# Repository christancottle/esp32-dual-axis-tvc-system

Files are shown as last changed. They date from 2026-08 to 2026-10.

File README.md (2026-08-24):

# ESP32 Dual-Axis Thrust Vector Control (TVC) Flight Computer

An embedded 6-DOF flight computer designed for active thrust vector control, real-time wireless ground station telemetry, and high-rate flash logging. Built around the **ESP32**, **MPU-6050** IMU, and **BMP280** barometric sensor.

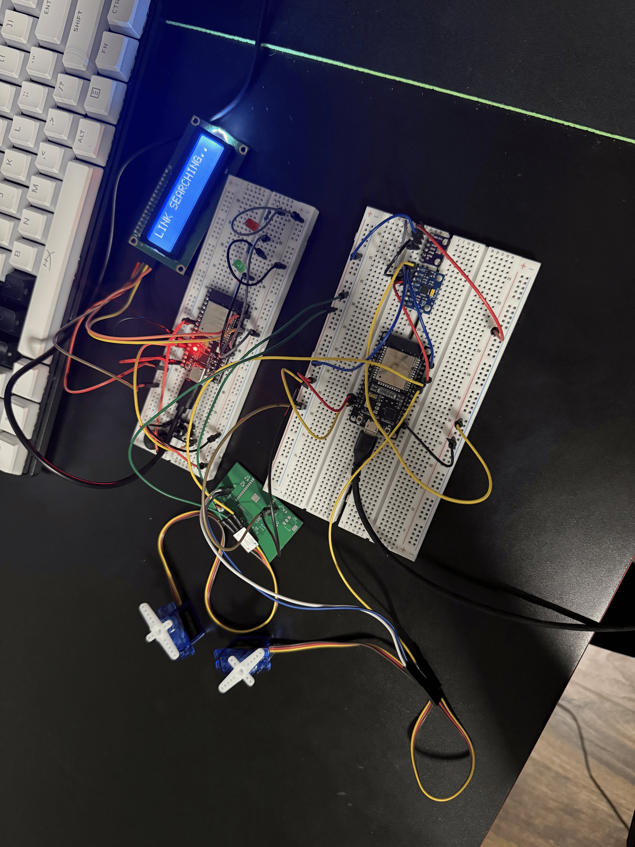
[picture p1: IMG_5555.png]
Flight Telemetry Plot


---

## Key Features

* **Dual-Axis Active Stabilization:** Controls Pitch and Yaw servos using sensor fusion logic bounded within $\pm 30^\circ$ deflection limits.
* **Low-Noise Filter Pipeline:** Employs an Exponential Moving Average (EMA) low-pass filter on orientation angles to eliminate motor servo jitter caused by high-G accelerometer noise.
* **High-Rate Flash Logging:** Writes telemetry data at ~30 Hz directly to onboard **LittleFS** physical flash memory with immediate buffer flushing (`logFile.flush()`) to prevent data loss during power brownouts.
* **5 Hz Wireless Telemetry:** Broadcasts telemetry packets over **ESP-NOW** to a ground telemetry station.
* **Deterministic State Machine:** Robust state engine (`ARMED` $\rightarrow$ `FLIGHT` $\rightarrow$ `DESCENT` $\rightarrow$ `LANDED`) with manual serial debug overrides (`reset` & `dump`).

---

## Hardware Specifications & Pinout

| Component | Interface / Pin | Description |
| :--- | :--- | :--- |
| **Microcontroller** | ESP32-WROOM-32 | Dual-core @ 240 MHz, LittleFS, ESP-NOW Wireless |
| **Pitch Servo** | GPIO 18 (PWM) | Dedicated PWM Timer 0 allocation (50 Hz) |
| **Yaw Servo** | GPIO 19 (PWM) | Dedicated PWM Timer 0 allocation (50 Hz) |
| **IMU (MPU-6050)** | I2C (SDA: 21, SCL: 22) | 6-DOF Accelerometer & Gyroscope ($\pm 8g$ range) |
| **Barometer (BMP280)**| I2C (Address 0x76/0x77) | High-precision altitude tracking with I2C recovery |

---

## Telemetry Log & Flight Performance

Flight performance data captured during test logging (stored in [`telemetry/espnowfile.csv`](espnowfile.csv)):

* **Peak Altitude:** `0.61 m` (Barometric filtered)
* **Peak Acceleration:** `1.40 g`
* **Log Sample Rate:** ~30 Hz (~33ms log interval)
* **Attitude Limits:** Pitch range $[-5.4^\circ, +35.7^\circ]$, Yaw range $[-0.8^\circ, +15.9^\circ]$

---

## Testing & Debugging Strategy

Building a custom avionics stack requires isolated validation of hardware, firmware, and wireless protocols before integration. The system was engineered and verified using a modular, step-by-step testing process:

### 1. Wireless Telemetry & Ground Station Validation
* **Mock Data Injection:** Before binding the actual ESP32 flight computer over ESP-NOW, the ground station display and receiving logic were validated by broadcasting simulated sine waves and randomized telemetry packets from a secondary microelectronics test rig.
* **Link Quality & Range Testing:** Verified packet delivery rates and RSSI stability to ensure zero-loss packet parsing prior to mounting hardware.

### 2. Sensor Calibration & Noise Filtering
* **Static Baseline Bench Calibration:** The BMP280 barometric pressure sensor was calibrated against local ambient pressure across multiple 10-sample rolling averages to establish an accurate zero-altitude reference.
* **Jitter Mitigation (EMA Filtering):** Raw MPU-6050 accelerometer readings exhibited high-frequency noise that translated into servo chatter. An Exponential Moving Average (EMA) low-pass filter ($\alpha = 0.15$) was implemented on the Yaw axis, successfully smoothing actuation without introducing control lag.

### 3. Flash Storage & Crash Resilience
* **LittleFS File Integrity Tests:** Initial testing revealed buffered writes were lost when power dropped during reset. The flight loop was updated to enforce immediate physical commits (`logFile.flush()`) right after writing telemetry rows.
* **Serial Log Dumping:** Integrated non-blocking serial commands (`dump` and `reset`) to easily extract flash logs to `.csv` format and re-zero altitude baselines between bench tests.

### 4. Hardware Safety & Servo Management
* **Shared PWM Timer Allocation:** Consolidated both servo channels onto ESP32 PWM Timer 0 to resolve hardware timer allocation conflicts and prevent signal dropping.
* **State Machine Latches:** Added persistent lock states in `LANDED` mode to keep servos centered and prevent unintentional actuation after flight completion.

---

## Repository Structure

```text
├── firmware/
│   └── TVC_Flight_Computer.ino     # Main ESP32 flight software
├── telemetry/
│   ├── espnowfile.csv              # Raw logged telemetry CSV dataset
│   └── plot_telemetry.py           # Python data analysis & plotting script
├── assets/
│   └── flight_telemetry_clean.png  # Generated telemetry visualization
└── README.md

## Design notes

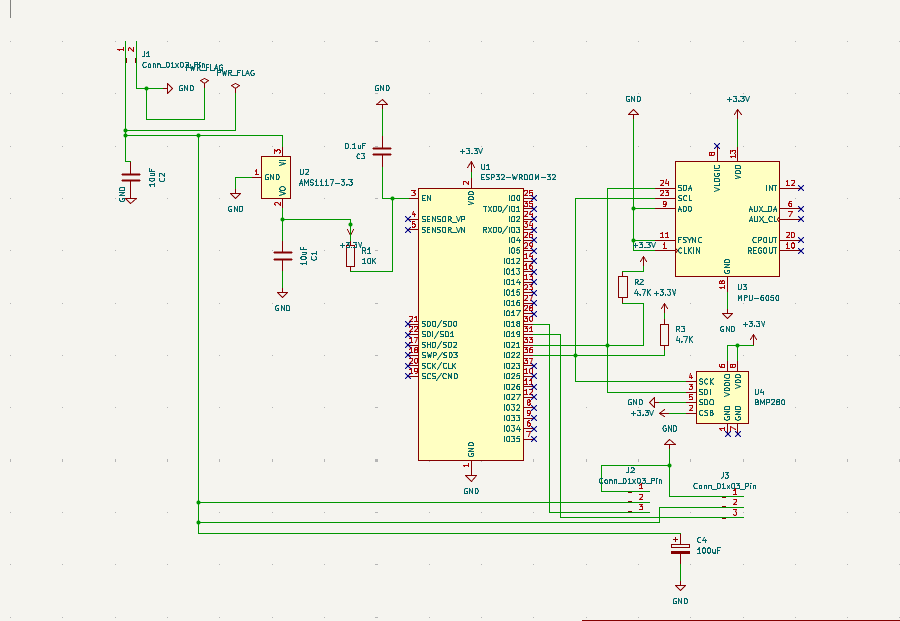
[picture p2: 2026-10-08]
Custom PCB Schematic.png

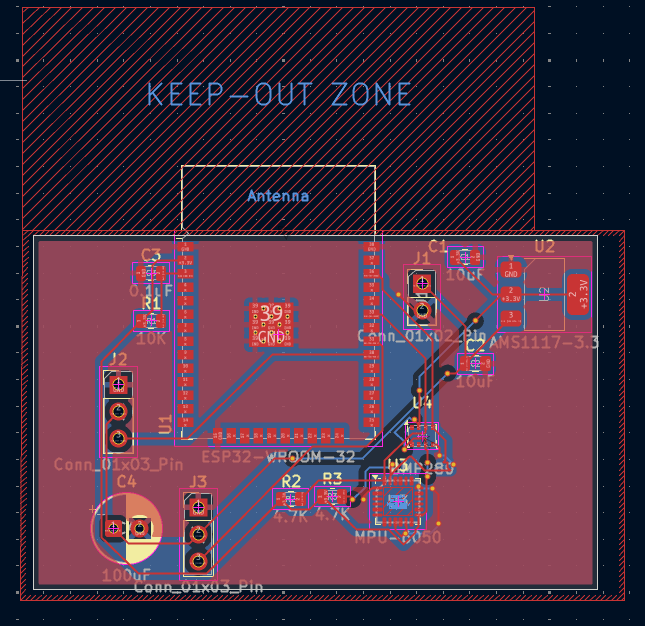
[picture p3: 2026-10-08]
Custom PCB editor.png

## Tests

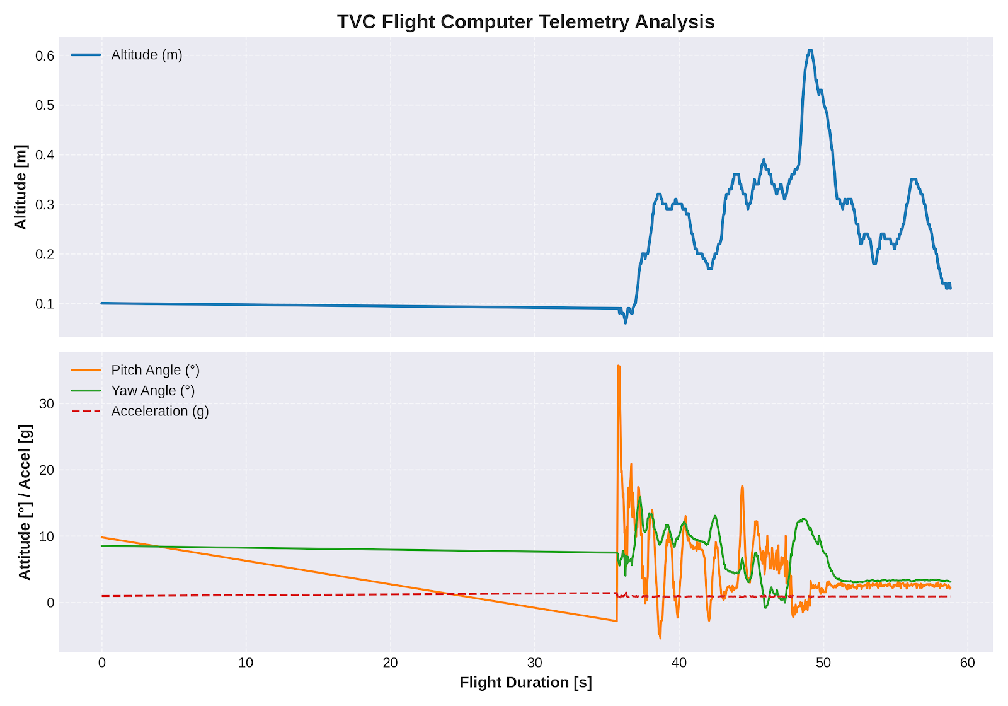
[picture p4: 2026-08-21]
Test_Run_Plots.png

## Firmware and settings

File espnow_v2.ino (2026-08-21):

#include <WiFi.h>
#include <esp_now.h>
#include <Wire.h>
#include <Adafruit_MPU6050.h>
#include <Adafruit_BMP280.h>
#include <Adafruit_Sensor.h>
#include <ESP32Servo.h>
#include <LittleFS.h>

// --- HARDWARE PIN DEFINITIONS ---
#define SERVO_PITCH_PIN 18 // Header J2
#define SERVO_YAW_PIN   19 // Header J3
#define SERVO_CENTER    90
#define SERVO_MAX_DEF   30

// --- GROUND STATION MAC ADDRESS ---
uint8_t broadcastAddress[] = {0xD4, 0xE9, 0xF4, 0xE1, 0xEC, 0xC0};

typedef struct TelemetryPacket {
    float pitch;
    float yaw;
    float altitude;
    uint8_t flightState; // 0=IDLE, 1=ARMED, 2=FLIGHT, 3=DESCENT, 4=LANDED
} TelemetryPacket;

TelemetryPacket txData;
esp_now_peer_info_t peerInfo;

Adafruit_MPU6050 mpu;
Adafruit_BMP280 bmp;
File logFile;

Servo pitchServo;
Servo yawServo;

unsigned long lastTxTime = 0;
unsigned long stateTimer = 0; 
float basePressure = 1013.25;
float maxAltitude = 0.0f;
float currentAltitude = 0.0f;
float filteredYaw = 0.0f; // EMA Filter memory for Yaw axis
bool bmpAvailable = false;

// Updated callback signature for ESP32 Core 3.3.8 / 3.x
void OnDataSent(const wifi_tx_info_t *tx_info, esp_now_send_status_t status) {
  // ESP-NOW Send Callback
}

// Full System & Altitude Baseline Reset
void resetSystem() {
  if (bmpAvailable) {
    float totalPressure = 0;
    for (int i = 0; i < 10; i++) {
      totalPressure += bmp.readPressure() / 100.0F;
      delay(10);
    }
    basePressure = totalPressure / 10.0F;
  }
  
  maxAltitude = 0.0f;
  currentAltitude = 0.0f;
  filteredYaw = 0.0f;
  txData.altitude = 0.0f;
  txData.flightState = 1; // ARMED mode
  stateTimer = millis();

  // Attach and center BOTH servos on reset
  pitchServo.write(SERVO_CENTER);
  yawServo.write(SERVO_CENTER);

  // LittleFS Log Initialization
  logFile = LittleFS.open("/flight_log.csv", FILE_WRITE);
  if (logFile) {
    logFile.println("Time_ms,State,Pitch_deg,Yaw_deg,Alt_m,AccMag");
    logFile.flush(); // Ensure header is written immediately
  }

  Serial.println("\n*** BENCH RESET COMPLETE: SERVOS CENTERED & ALTITUDE ZEROED ***\n");
}

void dumpFlashData() {
  Serial.println("\n--- DUMPING TELEMETRY LOG FROM LITTLEFS FLASH ---");
  
  // Close write buffer before reading to prevent file locks
  if (logFile) {
    logFile.flush();
    logFile.close();
  }

  File file = LittleFS.open("/flight_log.csv", FILE_READ);
  if (!file) {
    Serial.println("❌ Failed to open /flight_log.csv");
    return;
  }
  while (file.available()) {
    Serial.write(file.read());
  }
  file.close();
  Serial.println("--- END OF FLIGHT LOG DUMP ---\n");

  // Re-open in append mode for future operations
  logFile = LittleFS.open("/flight_log.csv", FILE_APPEND);
}

void setup() {
  Serial.begin(115200);

  // 1. Initialize LittleFS Flash Storage
  if (!LittleFS.begin(true)) {
    Serial.println("❌ LittleFS Storage Mount Failed!");
  } else {
    Serial.println("✅ LittleFS Storage Online.");
  }

  // 2. Optimized Servo Timer Allocation (Shared Timer 0 to eliminate jitter)
  ESP32PWM::allocateTimer(0);
  pitchServo.setPeriodHertz(50);
  yawServo.setPeriodHertz(50);
  
  pitchServo.attach(SERVO_PITCH_PIN, 500, 2400);
  yawServo.attach(SERVO_YAW_PIN, 500, 2400);

  pitchServo.write(SERVO_CENTER);
  yawServo.write(SERVO_CENTER);

  // 3. Initialize I2C Peripherals
  Wire.begin(21, 22);

  if (!mpu.begin()) {
    Serial.println("Warning: MPU6050 not detected!");
  } else {
    mpu.setAccelerometerRange(MPU6050_RANGE_8_G);
    Serial.println("✅ MPU6050 Online!");
  }

  if (bmp.begin(0x76) || bmp.begin(0x77)) {
    bmpAvailable = true;
    bmp.setSampling(Adafruit_BMP280::MODE_NORMAL,     
                    Adafruit_BMP280::SAMPLING_X2,     
                    Adafruit_BMP280::SAMPLING_X16,    
                    Adafruit_BMP280::FILTER_X16,      
                    Adafruit_BMP280::STANDBY_MS_1);   
    Serial.println("✅ BMP280 Online!");
  } else {
    Serial.println("Warning: BMP280 not detected!");
  }

  // 4. Initialize ESP-NOW
  WiFi.mode(WIFI_STA);

  if (esp_now_init() != ESP_OK) {
    Serial.println("Error initializing ESP-NOW");
    return;
  }

  esp_now_register_send_cb(OnDataSent);

  memcpy(peerInfo.peer_addr, broadcastAddress, 6);
  peerInfo.channel = 0;  
  peerInfo.encrypt = false;
  
  if (esp_now_add_peer(&peerInfo) != ESP_OK) {
    Serial.println("Failed to add peer");
    return;
  }

  resetSystem();
}

void loop() {
  // Serial command parser
  if (Serial.available() > 0) {
    String input = Serial.readStringUntil('\n');
    input.trim();
    if (input.equalsIgnoreCase("reset")) {
      resetSystem();
    } else if (input.equalsIgnoreCase("dump")) {
      dumpFlashData();
    }
  }

  // Read MPU-6050
  sensors_event_t a, g, temp;
  mpu.getEvent(&a, &g, &temp);

  // Pitch calculation
  txData.pitch = atan2(a.acceleration.y, a.acceleration.z) * 180.0 / M_PI;

  // Yaw calculation with EMA Low-Pass Filter (0.15 alpha) to eliminate motor jitter
  float rawYaw = atan2(-a.acceleration.x, sqrt(a.acceleration.y * a.acceleration.y + a.acceleration.z * a.acceleration.z)) * 180.0 / M_PI;
  filteredYaw = (0.15f * rawYaw) + (0.85f * filteredYaw);
  txData.yaw = filteredYaw;

  // Read BMP280
  if (bmpAvailable) {
    float rawAltitude = bmp.readAltitude(basePressure);

    if (rawAltitude > 2000.0 || isnan(rawAltitude) || rawAltitude < -50.0f) {
      Wire.begin(21, 22);
      bmp.begin(0x76);
      delay(5);
      rawAltitude = bmp.readAltitude(basePressure);
    }

    currentAltitude = (0.80f * currentAltitude) + (0.20f * rawAltitude);
    if (currentAltitude < 0.0f) currentAltitude = 0.0f;
    txData.altitude = currentAltitude;
  }

  // Calculate Total Acceleration Vector Magnitude
  float accelMag = sqrt(a.acceleration.x * a.acceleration.x + 
                        a.acceleration.y * a.acceleration.y + 
                        a.acceleration.z * a.acceleration.z);

  // --- DUAL-AXIS ACTIVE TVC SERVO CONTROL ---
  if (txData.flightState == 1 || txData.flightState == 2) { 
    // Active Stabilization during ARMED & FLIGHT
    int pCmd = constrain(SERVO_CENTER - (int)txData.pitch, SERVO_CENTER - SERVO_MAX_DEF, SERVO_CENTER + SERVO_MAX_DEF);
    int yCmd = constrain(SERVO_CENTER + (int)txData.yaw,   SERVO_CENTER - SERVO_MAX_DEF, SERVO_CENTER + SERVO_MAX_DEF);

    pitchServo.write(pCmd);
    yawServo.write(yCmd);
  } else {
    // Lock Servos Neutral in IDLE, DESCENT, or LANDED
    pitchServo.write(SERVO_CENTER);
    yawServo.write(SERVO_CENTER);
  }

  // --- REVISED FLIGHT STATE MACHINE ---
  switch (txData.flightState) {
    case 0: // IDLE
      break;

    case 1: // ARMED
      if (accelMag > 13.0 || txData.altitude > 0.30f) { 
        txData.flightState = 2; // FLIGHT
        maxAltitude = txData.altitude;
        stateTimer = millis();
        Serial.println(">>> LAUNCH DETECTED! SWITCHING TO FLIGHT MODE <<<");
      }
      break;

    case 2: // FLIGHT / ASCENT
      if (txData.altitude > maxAltitude) {
        maxAltitude = txData.altitude;
        stateTimer = millis(); // Reset timer while ascending
      }

      // Robust bench test apogee criteria: >1.8s peak dwell time AND >0.5m altitude reached
      if (millis() - stateTimer > 1800 && txData.altitude > 0.30f) {
        txData.flightState = 3; // DESCENT
        stateTimer = millis();
        Serial.println(">>> APOGEE DETECTED! ENTERING DESCENT MODE <<<");
      }
      break;

    case 3: // DESCENT
      if (txData.altitude < 0.20f) {
        if (millis() - stateTimer > 1000) {
          txData.flightState = 4; // LANDED
          stateTimer = millis();
          Serial.println(">>> TOUCHDOWN DETECTED! VEHICLE LANDED SAFELY. DATA READY FOR 'dump' <<<");
        }
      } else {
        stateTimer = millis();
      }
      break;

    case 4: // LANDED
      // Hold state safely without auto-resetting
      break;
  }

  // Telemetry Logging with Immediate Flash Flushing
  if (logFile && (txData.flightState == 2 || txData.flightState == 3)) {
    logFile.printf("%lu,%d,%.2f,%.2f,%.2f,%.2f\n", 
                    millis(), txData.flightState, txData.pitch, txData.yaw, txData.altitude, accelMag);
    logFile.flush(); // Critical: Commit buffer directly to physical flash
  }

  // Wireless ESP-NOW Telemetry Transmission (5 Hz)
  if (millis() - lastTxTime >= 200) {
    lastTxTime = millis();
    esp_now_send(broadcastAddress, (uint8_t *) &txData, sizeof(txData));
  }
}

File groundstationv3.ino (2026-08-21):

#include <WiFi.h>
#include <esp_now.h>
#include <Wire.h>
#include <LiquidCrystal_I2C.h>

// --- HARDWARE PIN DEFINITIONS ---
#define GREEN_LED_PIN 16
#define RED_LED_PIN   17
#define BUZZER_PIN    25
#define BUTTON_PIN    13

// LCD Initialization (Default Address: 0x27)
LiquidCrystal_I2C lcd(0x27, 16, 2);

// Telemetry Data Structure - MUST MATCH FLIGHT COMPUTER
typedef struct TelemetryPacket {
    float pitch;
    float yaw;
    float altitude;
    uint8_t flightState; // 0=IDLE, 1=ARMED, 2=FLIGHT, 3=DESCENT
} TelemetryPacket;

TelemetryPacket rxData;
const char* stateNames[] = {"IDLE", "ARM ", "FLY ", "DESC"};

unsigned long lastPacketTime = 0;
uint8_t lastState = 255;
bool greenLedState = false;
bool newPacketReceived = false;

// Audio alert helper function
void beep(int frequency, int durationMs) {
    tone(BUZZER_PIN, frequency, durationMs);
    delay(durationMs);
    noTone(BUZZER_PIN);
}

// ESP-NOW Receive Callback
void OnDataRecv(const esp_now_recv_info *info, const uint8_t *incomingData, int len) {
    memcpy(&rxData, incomingData, sizeof(rxData));
    lastPacketTime = millis();
    newPacketReceived = true;
}

void setup() {
    Serial.begin(115200);

    // Initialize Pins
    pinMode(GREEN_LED_PIN, OUTPUT);
    pinMode(RED_LED_PIN, OUTPUT);
    pinMode(BUZZER_PIN, OUTPUT);
    pinMode(BUTTON_PIN, INPUT_PULLUP);

    // Startup Tones
    beep(1000, 100);
    delay(100);
    beep(1500, 150);

    // Initialize LCD
    Wire.begin(21, 22);
    lcd.init();
    lcd.backlight();
    
    lcd.setCursor(0, 0);
    lcd.print("GND STATION v3.0");
    lcd.setCursor(0, 1);
    lcd.print("AWAITING ESP-NOW");

    // Initialize ESP-NOW
    WiFi.mode(WIFI_STA);

    if (esp_now_init() != ESP_OK) {
        Serial.println("Error initializing ESP-NOW");
        lcd.setCursor(0, 1);
        lcd.print("ESP-NOW ERROR   ");
        return;
    }

    esp_now_register_recv_cb(OnDataRecv);

    delay(1500);
    lcd.clear();
    lcd.setCursor(0, 0);
    lcd.print("LINK SEARCHING..");
}

void loop() {
    // Process Incoming Telemetry
    if (newPacketReceived) {
        newPacketReceived = false;

        // Heartbeat LED
        greenLedState = !greenLedState;
        digitalWrite(GREEN_LED_PIN, greenLedState ? HIGH : LOW);

        // CSV Serial Logging
        Serial.printf("TELEM,%.2f,%.2f,%.2f,%d\n", rxData.pitch, rxData.yaw, rxData.altitude, rxData.flightState);

        // Status LED
        digitalWrite(RED_LED_PIN, (rxData.flightState == 1 || rxData.flightState == 2) ? HIGH : LOW);

        // State Transition Audio Alerts
        if (rxData.flightState != lastState) {
            lastState = rxData.flightState;
            
            if (rxData.flightState == 1) { 
                beep(1200, 100); delay(50); beep(1200, 100); // Double Beep (ARMED)
            } 
            else if (rxData.flightState == 2) { 
                beep(1800, 300); // High Launch Tone (FLIGHT)
            } 
            else if (rxData.flightState == 0) { 
                beep(400, 200);  // Low Return Tone (IDLE)
            }
        }

        // Update LCD Display with Sub-Meter Decimal Precision
        lcd.setCursor(0, 0);
        lcd.printf("P:%5.1f Y:%5.1f", rxData.pitch, rxData.yaw);

        lcd.setCursor(0, 1);
        lcd.printf("A:%4.1fm [%s]", rxData.altitude, stateNames[rxData.flightState]);
    }

    // Link Timeout Detector (3 seconds)
    if (millis() - lastPacketTime > 3000 && lastPacketTime != 0) {
        lcd.setCursor(0, 0);
        lcd.print("  SIGNAL LOST!  ");
        lcd.setCursor(0, 1);
        lcd.print(" CHECK TRANSMIT ");
        digitalWrite(RED_LED_PIN, LOW);
        digitalWrite(GREEN_LED_PIN, LOW);
    }

    // Ground Station Button Trigger
    if (digitalRead(BUTTON_PIN) == LOW) {
        beep(2000, 50);
        Serial.println("GND_CMD: USER_INTERRUPT_MARKER");
        delay(200);
    }

    delay(20);
}

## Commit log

2026-10-08 Rename Screenshot 2026-10-07 213058.png to Custom PCB Schematic.png
2026-10-08 Rename Screenshot 2026-10-07 213252.png to Custom PCB editor.png
